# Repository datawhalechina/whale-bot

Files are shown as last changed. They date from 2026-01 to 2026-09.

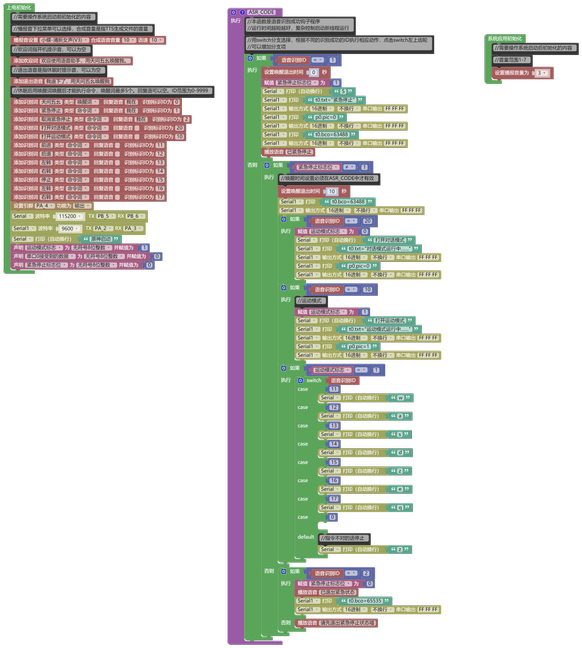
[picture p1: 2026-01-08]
WhaleBot智能鲸鱼小车/hardware/天问ASRPRO/天问ASRPRO.png

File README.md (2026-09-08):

# 🐳 WhaleBot 智能鲸鱼小车 (ESP32-S3 AI Robot)

**WhaleBot** 是一个基于 **ESP32-S3** 的全向移动 AI 机器人项目。它集成了 **Coze (扣子) 大模型**、**百度语音技术**、**麦克纳姆轮**全向运动控制以及**串口触摸屏**，实现了“听、说、想、动、看”一体化的智能交互体验。

---

### 🤝 Datawhale x 星芯工坊 | AI 硬件跟班学习

## 📚 开发教程 (Documentation)

本项目联合国内最大的 AI 开源社区 **Datawhale** 发起【AI 硬件入门跟班学习】活动！

Datawhale 致力于构建“For the learner, 构建 AI 学习者的开源社区”，汇聚了众多 AI 领域的专家与爱好者。

本次课程将带领大家从零开始，手搓一台属于自己的 AI 机器人。

我们编写了保姆级的开发教程，涵盖硬件选型、PCB 设计原理、代码注释及组装教程，并且会在后续配上视频教程。

👉 DataWhale官网教程链接**https://www.datawhale.cn/learn/summary/268** 👈

👉DataWhale跟班学习群👈

  a497525bfc7f890d2fe31357c8119220

如果这一期跟班学习人数已满怎么办？没关系，你可以加入我们的项目交流微信群，同样可以得到技术和硬件支持！

  

### 🛍️ 新手无忧套件

为了让初学者免去元器件采购发货慢、型号买错的烦恼，我们提供了**一站式全套件**（包含 3D 打印外壳、PCB 成品/半成品、电机、电池及所有电子料）。这些物料消息会在跟班学习官方群和我们的项目讨论群中同步更新，可以在群内咨询~

---

## 🛠️ 硬件架构

### 硬件清单
*   **主控**：ESP32-S3-DevKitC (N16R8)
*   **驱动**：TB6612FNG 2片
*   **执行器**：N20 减速电机 (12V 300RPM) 4个 + 麦克纳姆轮 4个（一套）
*   **音频**：INMP441 麦克风 + MAX98357A 功放 ＋ 
*   **电源**：12V 锂电池 + TPS5430 降压模块
*   **交互**：串口触摸屏 / 天问 ASRPRO 开发板
*   ps：电子器件部分如需自行购买请参考前文提到的“Datawhale官网开发教程”（后简称“教程”）第一大章“DIY所需硬件”的购买推荐
*   **外形**：详见docs/外壳打印文件
*   **PCB**：详见hardware/PCB及原理图

---

## 💻 复刻：快速上手指南

### 一. 硬件部分组装
1.准备好pcb板，按照板上引脚位置指示连接电子器件。
ps：若自行打板请参照hardware/Bom表购买相关电子元件并自行焊接。
2.外壳组装，外壳前后端与底板留有固定贴，方便拆卸调试，外壳文件详见docs/外壳打印。

### 二. esp32-s3程序部分
1.下载Arduino IDE（推荐版本2.1.4及以上）。
2.下载esp32芯片包，离线下载包位于firmware/esp32芯片包，如果不会离线下载请参考“教程”第三大章“软件部分”。
3.安装支持库如下
<base64.hpp> （建议版本1.3.0） 
<ArduinoJson.h> （建议版本7.4.1）
<UrlEncode.h> （建议版本1.0.1）
4.在烧录代码前按照下图所示进行相应选项的勾选！！

代码文件位于firmware/WhaleBot_Main.ino。

---

## 🤝 致谢

本项目由MeetAI实验室发起并完成项目开发，历时9个月最终成功制作出WhaleBot AI鲸鱼小车，并制作了一套完整的教程。在此衷心感谢Datawhale社区，全体参与开发的小伙伴，提供帮助的指导老师和同仁们。MeetAI实验室是来自福州大学的计算机学院的实验室，创立于2024年，致力于打造一个有趣好玩多元的104。


                                                
    实验室的开发者们

开发者名单

项目总负责人：林镐轩

项目开发：林镐轩，尚启峰，解皓喆

二次开发：林镐轩，Neil·Bauman，猫猫草，gtxylt，kyle

教程制作：林镐轩，kyle，小班，青莳与空，Neil·Bauman，猫猫草，李诗语，刘宣佑

如果你觉得这个项目有趣，请点击右上角的 ⭐️ **Star** 支持我们！

## 📄 License

[MIT License](LICENSE) © 2024 StarChip Workshop (星芯工坊)
```

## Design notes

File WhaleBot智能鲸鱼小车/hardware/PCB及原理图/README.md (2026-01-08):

# 🐋 WhaleBot 硬件设计与焊接指南

本文档说明了 WhaleBot 智能小车的硬件架构、PCB 设计规范及组装流程。

> 🌟 **欢迎加入【星芯工坊】社区**
> 如果你在制作过程中遇到了硬件调试疑难或希望参与新功能共创，欢迎加入：
> *   **群名称**：星芯工坊
> *   **QQ群号**：[571656123]

---

## 📐 1. PCB 设计与布线规范

在根据原理图进行 PCB 布局布线时，请务必遵循以下物理特性要求：

### 1.1 电源路径与线宽
根据原理图，电路包含三级电压，需按电流大小分配线宽：
*   **12V 动力线 (VBAT_12V)**：由 DC-005 输入，经过 SW1 开关和 F1 保险丝，直通两个 TB6612 的 VM 脚。建议线宽 **≥ 40mil**。
*   **5V 主供电 (+5V)**：经 U78 一级降压输出，供给 ASRPRO、串口屏和 MAX98357 功放。建议线宽 **≥ 25mil**。
*   **3.3V 逻辑电 (3V3)**：由 H78 (AMS1117 模块) 二级降压输出，供给 ESP32-S3 和 INMP441 麦克风。建议线宽 **≥ 15mil**。

### 1.2 信号完整性布局
1.  **音频保护**：U5 (麦克风) 和 U6 (功放) 属于敏感模拟/数字混合信号，应尽量远离 U3/U4 (电机驱动) 的高频 PWM 走线。
2.  **地线铺铜**：建议全板大面积铺 GND 铜箔，以降低阻抗并辅助散热。

---

## 🧩 2. 元器件清单 (BOM)

请对照原理图各功能框图准备以下元件：

### A. 核心模块
*   **MCU**: ESP32S3-DevKitC - 1个
*   **语音模块**: ASRPRO51 天问开发板 - 1个
*   **电机驱动**: TB6612FNG (正面插接) - 2个 (U3, U4)

### B. 电源与保护
*   **保险丝 (F1)**: SMD0805-050C-30V (0.5A/30V 自恢复) - 1个
*   **防反接/续流 (D1, D2)**: SS34 (肖特基二极管) - 2个
*   **一级降压 (U78)**: 12V 转 5V 降压模块 (4引脚封装) - 1个
*   **二级降压 (H78)**: PM254V-11-03 (AMS1117-3.3 模块) - 1个
*   **滤波电容 (C1)**: 100nF (104) 陶瓷电容 - 1个
*   **接插件**: DC-005 电源座、KCD1-101 开关、KF301R-5.0-2P 端子 (4个)

### C. 音频与交互
*   **麦克风 (U5)**: INMP441 I2S 模块 - 1个
*   **功放 (U6)**: MAX98357A I2S 模块 - 1个
*   **串口屏接口 (H1)**: 2.54mm 4P 排针 - 1个

---

## 🔌 3. 硬件引脚对应表 (严格对照原理图)

### 3.1 电机驱动 (ESP32 -> TB6612)
| 轮位 | 引脚功能 | ESP32-S3 引脚 |
| :--- | :--- | :--- |
| **左前 (FL)** | AIN1/AIN2 / PWMA | IO41 / IO42 / **IO40** |
| **右前 (FR)** | BIN1/BIN2 / PWMB | IO39 / IO38 / **IO48** |
| **左后 (RL)** | AIN1/AIN2 / PWMA | IO11 / IO10 / **IO12** |
| **右后 (RR)** | BIN1/BIN2 / PWMB | IO14 / IO13 / **IO21** |

### 3.2 音频系统 (ESP32 I2S)
*   **麦克风 (INMP441)**: WS -> **IO5** | SD -> **IO6** | SCK -> **IO4**
*   **功放 (MAX98357)**: LRC -> **IO16** | BCLK -> **IO8** | DIN -> **IO7**

### 3.3 串口通信 (ESP32-ASRPRO-屏幕)
*   **ESP32 侧**: TX -> **IO17** | RX -> **IO18**
*   **通信对象**: 该总线同时挂载 ASRPRO 的 PA2/PA3 及串口屏的 TX/RX。

---

## 👨‍🏭 4. 焊接与上电检查流程

### 4.1 焊接要点
1.  **高度优先**：先焊接贴片 F1、D1、D2 和 C1，再焊接排母和接线端子。
2.  **方向确认**：
    *   **D1/D2** 极性带杠的一端为负极，严禁焊反。
    *   **TB6612** 模块安装时，确认其 VM 脚对应原理图中的 12V 供电方向。

### 4.2 关键电压测试 (通电前必测)
在插入 ESP32 和模块前，接入 12V 电源，使用万用表测量排母：
1.  测量 `+5V` 与 `GND`：应稳定在 **5V ± 0.2V**。
2.  测量 `3V3` 与 `GND`：应稳定在 **3.3V ± 0.1V**。
3.  测量 `VM` (电机驱动排母第16脚)：应为 **12V** 电池电压。

---

## ⚠️ 常见问题排查 (FAQ)

**Q1: 电机不工作，但代码逻辑正常？**
*   检查 TB6612 的 `STBY` 引脚是否正确接入 3.3V。
*   检查 F1 保险丝是否因瞬时大电流熔断。

**Q2: 麦克风有严重杂音？**
*   检查 U5 的电源是否接在 3.3V（原理图设计），若误接 5V 会导致芯片性能衰减或烧毁。
*   确认电路板上麦克风附近的走线是否有高频干扰。

**Q3: 语音模块与串口屏冲突？**
*   原理图上 ASRPRO 与屏幕共用总线。请确保两者不会同时发送数据，或通过代码分配不同的握手逻辑。

---

**星芯工坊 - WhaleBot 硬件小组**
*版本：V1.0 | 日期：2026-01-07*

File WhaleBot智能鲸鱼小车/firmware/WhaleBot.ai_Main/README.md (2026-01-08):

# 🐋 WhaleBot.ai 固件说明 (WhaleBot.ai_Main)

本文档详细说明了 WhaleBot 智能鲸鱼小车主控程序（`WhaleBot.ai_Main.ino`）的编译环境配置、依赖库安装及代码逻辑。

## 🛠️ 1. 开发环境配置 (Arduino IDE)

本项目基于 **ESP32-S3** 芯片开发，为了确保程序能正常运行（特别是录音和长文本处理），**必须**正确配置 PSRAM。

### 1.1 安装开发板支持包
*   打开 Arduino IDE -> `文件` -> `首选项`。
*   在“附加开发板管理器网址”中添加：
    `https://espressif.github.io/arduino-esp32/package_esp32_index.json`
*   点击 `工具` -> `开发板` -> `开发板管理器`，搜索 **ESP32 by Espressif System** 并安装 (推荐版本 3.3.5)。

### 1.2 关键参数配置 (至关重要 ⚠️)
请按照以下步骤配置 `工具 (Tools)` 菜单：

1.  **开发板 (Board)**: 选择 `ESP32S3 Dev Module`。
2.  **USB CDC On Boot**: 选择 `Enabled` (这样串口监视器才能看到打印信息)。
3.  **Flash Mode**: 选择 `QIO 80MHz`。
4.  **PSRAM**: **必须选择 `OPI PSRAM`**。
    *   *解释*：本项目录音缓存和 Base64 编码需要大量内存，内部 SRAM 不够用，必须开启外部 8MB PSRAM。
    *   *注意*：开启 OPI PSRAM 后，GPIO 35, 36, 37 将被占用，不可用于其他功能（代码中已避开这些引脚）。

---

## 📚 2. 依赖库安装

在编译代码前，请在 Arduino IDE 的 `项目` -> `加载库` -> `管理库` 中搜索并安装以下第三方库：

*   **ArduinoJson** (必选)
    *   说明：用于解析 Coze 大模型和百度 API 返回的 JSON 数据。
    *   版本：推荐 6.x 版本。
*   **UrlEncode** (必选)
    *   说明：用于将中文文本转换为 URL 编码格式，以便发送 HTTP 请求。

*注：`HTTPClient`, `WiFi`, `driver/i2s` 等库包含在 ESP32 开发板包中，无需单独下载。*

---

## 🔌 3. 硬件引脚速查表 (Pinout)

如果在画 PCB 或连线时需要参考，请以本表为准（与代码定义一致）。

### 3.1 外部接口 (串口通信)
用于连接天问 ASR 或蓝牙模块：
*   **TX (模块端)** -> 接 ESP32 **GPIO 18** (RX)
*   **RX (模块端)** -> 接 ESP32 **GPIO 17** (TX)

### 3.2 音频系统 (I2S)

**麦克风 (INMP441)**
*   **SCK** (时钟) -> **GPIO 4**
*   **WS** (字选) -> **GPIO 5**
*   **SD** (数据) -> **GPIO 6**

**功放 (MAX98357A)**
*   **BCLK** (位时钟) -> **GPIO 8** (*注意：此处非默认的15*)
*   **LRC** (左右声道) -> **GPIO 16**
*   **DIN** (数据入) -> **GPIO 7**

### 3.3 电机驱动 (TB6612 x2)

**左前轮 (FL)**
*   IN1: **42**
*   IN2: **41**
*   PWM: **40**

**右前轮 (FR)**
*   IN1: **39**
*   IN2: **38**
*   PWM: **48** (*注意：避开了 OPI PSRAM 引脚*)

**左后轮 (RL)**
*   IN1: **10**
*   IN2: **11**
*   PWM: **12**

**右后轮 (RR)**
*   IN1: **13**
*   IN2: **14**
*   PWM: **21**

---

## 🧠 4. 代码逻辑架构

本固件采用 **状态机 (State Machine)** 架构，确保小车在不同模式下互不干扰。

### 4.1 核心状态
1.  **MODE_IDLE (待机)**
    *   停止所有电机和录音，仅监听串口指令。
    *   收到 `停止` 指令后强制回到此状态。
2.  **MODE_VOICE (语音)**
    *   进入后等待 `开始聊天` 指令触发。
    *   **流程**：VAD 录音 (说话即录，说完即停) -> 回放录音 -> 百度 STT (转文字) -> Coze LLM (AI思考) -> 百度 TTS (语音合成并播放)。
3.  **MODE_MOTION (运动)**
    *   接收串口 `W/A/S/D` 等指令控制麦克纳姆轮全向移动。
    *   支持 `点动模式` (动2秒自动停) 和 `持续模式` (一直动直到停止)。

### 4.2 串口通信协议
*   **波特率**: `115200`
*   **结束符**: 每一条指令必须以换行符 `\n` 结尾。
*   **指令示例**:
    *   `打开对话模式` —— 进入语音状态
    *   `开始聊天` —— 触发录音
    *   `W` —— 前进
    *   `停止` —— 全局急停

---

## 📝 5. 使用前必读

在上传代码前，请务必在 `WhaleBot.ai_Main.ino` 文件的顶部 **用户配置区** 填入你自己的信息：

1.  **WiFi**: 修改 SSID 和 密码。
2.  **百度智能云**: 填入 API Key 和 Secret Key (用于语音服务)。
3.  **Coze (扣子)**: 填入 PAT Token 和 Bot ID (用于 AI 对话)。

> 详细的 API 获取教程请查看目录下的：`firmware/百度 和 COZE API获取/Readme.md`

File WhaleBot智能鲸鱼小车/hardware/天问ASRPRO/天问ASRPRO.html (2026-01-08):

# 🎙️ ASRPRO 2.0 + 天问 Block 开发指南

  

本文档旨在为开发者提供 ASRPRO 2.0 语音模块与天问 Block 开发平台的集成概览。重点阐述系统架构、核心运行逻辑以及外设通信的基础配置。

## 1. 平台概述 (Overview)

### 🧩 ASRPRO 2.0 硬件平台

ASRPRO 是一款高度集成的离线语音识别开发板，专为语音交互场景设计。其硬件架构具有以下特点：

- 核心集成：板载高性能语音处理模块，内置神经网络加速单元。
- 声学前端：集成高灵敏度麦克风接口与功率放大器（Power Amp），支持直接驱动扬声器。
- 丰富外设：
  - 通信接口：集成串口 (UART)、IIC 总线。
  - 控制与采集：提供 ADC（模数转换）、硬件定时器等资源。
- 主要用途：广泛应用于离线语音识别、简单的语音对话交互以及智能家居控制。

### 💻 天问 Block 软件平台

天问 Block (Tianwen Block) 是 ASRPRO 系列的官方开发环境，旨在通过图形化界面降低开发门槛。

- 编程模式：采用类 Sketch、Mixly 的积木式图形化编程界面。
- 功能实现：支持通过拖拽积木实现复杂的逻辑控制，底层自动编译为高效的执行代码。

## 2. 核心运行机制 (Core Mechanism)

理解 ASRPRO 的程序生命周期是开发的关键。在天问 Block 环境下，系统的执行逻辑遵循以下严格顺序：

初始化阶段 系统上电后，首先执行上电初始化，紧接着执行系统应用初始化。

正常运行阶段 完成初始化后，系统进入正常运行状态（主循环），处于持续监听模式。

事件触发机制 当系统检测到语音唤醒或识别到预设的命令词时，会执行 asrcore 核心程序一次。所有的语音识别后处理逻辑（如回复语播放、信号输出）均应在此事件中实现。

## 3. 外设与通信配置 (Peripherals & Communication)

本项目主要利用 串口 (UART) 外设实现 ASRPRO 与外部设备（如串口屏、ESP32-S3 主控）的数据交互。

### 🔌 串口资源概览

ASRPRO 硬件上共包含 3 个独立串口，开发者需根据实际需求进行配置。

### ⚙️ 配置规范

在使用串口外设前，必须在初始化阶段完成以下参数定义：

1. 初始化要求：
  - 串口功能默认关闭，必须在程序启动时显式执行初始化模块。
2. 波特率配置：
  - 支持配置为固定的标准波特率档位1200，4800，9600，19200，38400，57600，115200，推荐配置为最高115200。
  - 注意：通信双方的波特率必须保持严格一致。
3. 引脚定义：
  - 串口的 TX/RX 引脚由硬件外设控制器直接决定。
  - 不可修改性：引脚映射是固定的，在使用时，需要注意和现有的引脚冲突情况。

你好

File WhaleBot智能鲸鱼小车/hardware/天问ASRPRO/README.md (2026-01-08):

# 🎙️ ASRPRO 2.0 + 天问 Block 开发指南

  

本文档旨在为开发者提供 ASRPRO 2.0 语音模块与天问 Block 开发平台的集成概览。重点阐述系统架构、核心运行逻辑以及外设通信的基础配置。

---

## 1. 平台概述 (Overview)

### 🧩 ASRPRO 2.0 硬件平台
ASRPRO 是一款高度集成的离线语音识别开发板，专为语音交互场景设计。其硬件架构具有以下特点：

*   **核心集成**：板载高性能语音处理模块，内置神经网络加速单元。
*   **声学前端**：集成高灵敏度麦克风接口与功率放大器（Power Amp），支持直接驱动扬声器。
*   **丰富外设**：
    *   **通信接口**：集成串口 (UART)、IIC 总线。
    *   **控制与采集**：提供 ADC（模数转换）、硬件定时器等资源。
*   **主要用途**：广泛应用于离线语音识别、简单的语音对话交互以及智能家居控制。

### 💻 天问 Block 软件平台
天问 Block (Tianwen Block) 是 ASRPRO 系列的官方开发环境，旨在通过图形化界面降低开发门槛。

*   **编程模式**：采用类 Sketch、Mixly 的积木式图形化编程界面。
*   **功能实现**：支持通过拖拽积木实现复杂的逻辑控制，底层自动编译为高效的执行代码。

---

## 2. 核心运行机制 (Core Mechanism)

理解 ASRPRO 的程序生命周期是开发的关键。在天问 Block 环境下，系统的执行逻辑遵循以下严格顺序：

> **初始化阶段**
> 系统上电后，首先执行**上电初始化**，紧接着执行**系统应用初始化**。

> **正常运行阶段**
> 完成初始化后，系统进入正常运行状态（主循环），处于持续监听模式。

> **事件触发机制**
> 当系统检测到**语音唤醒**或识别到预设的**命令词**时，会执行 `asrcore` 核心程序一次。所有的语音识别后处理逻辑（如回复语播放、信号输出）均应在此事件中实现。

---

## 3. 外设与通信配置 (Peripherals & Communication)

本项目主要利用 **串口 (UART)** 外设实现 ASRPRO 与外部设备（如串口屏、ESP32-S3 主控）的数据交互。

### 🔌 串口资源概览
ASRPRO 硬件上共包含 **3 个独立串口**，开发者需根据实际需求进行配置。

### ⚙️ 配置规范
在使用串口外设前，必须在初始化阶段完成以下参数定义：

1.  **初始化要求**：
    *   串口功能默认关闭，必须在程序启动时显式执行初始化模块。

2.  **波特率配置**：
    *   支持配置为固定的标准波特率档位1200，4800，9600，19200，38400，57600，115200，推荐配置为最高115200。
    *   *注意：通信双方的波特率必须保持严格一致。*

3.  **引脚定义**：
    *   串口的 TX/RX 引脚由硬件外设控制器直接决定。
    *   **不可修改性**：引脚映射是固定的，在使用时，需要注意和现有的引脚冲突情况。

---

## 4. 语音指令表 (Voice Command Table)

以下为本项目预设的语音识别指令集。指令分为**唤醒**、**安全控制**、**模式切换**及**运动控制**四大类。

| 语音指令 | 执行内容 (TTS/Action) | 指令摘要 |
| :--- | :--- | :--- |
| **天问五幺** | 🔊 播报：“我在” | **设备唤醒词**，用于激活语音交互状态。 |
| **紧急停止** | 🔇 无语音回复 | **最高优先级指令**，触发急停逻辑，中断当前所有动作。 |
| **取消紧急停止** | 🔇 无语音回复 | 解除急停锁定状态，恢复设备待机。 |
| **打开对话模式** | 🔇 无语音回复 | 切换系统至对话交互逻辑，准备接收聊天指令。 |
| **开始聊天** | 🔇 无语音回复 | 触发聊天功能模块。 |
| **打开运动模式** | 🔇 无语音回复 | 切换系统至运动控制逻辑，激活电机/底盘控制。 |
| **前进** | 🔇 无语音回复 | 控制设备向前移动。 |
| **后退** | 🔇 无语音回复 | 控制设备向后移动。 |
| **左平移** | 🔇 无语音回复 | 控制麦克纳姆轮/全向轮底盘向左平移。 |
| **右平移** | 🔇 无语音回复 | 控制麦克纳姆轮/全向轮底盘向右平移。 |
| **停止** | 🔇 无语音回复 | 结束当前移动指令，设备归零/刹车。 |
| **左转** | 🔇 无语音回复 | 控制设备原地向左旋转。 |
| **右转** | 🔇 无语音回复 | 控制设备原地向右旋转。 |
| **设置为持续运动状态** | 🔇 无语音回复 | 更改运动逻辑为“保持当前动作直到收到停止指令”。 |
| **退出持续运动状态** | 🔇 无语音回复 | 恢复默认运动逻辑（如点动模式或定时停止）。 |

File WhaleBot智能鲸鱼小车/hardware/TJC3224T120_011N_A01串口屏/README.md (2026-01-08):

这份文档已经按照你的要求进行了重新架构和内容扩充，采用了更加专业、美观的 Markdown 格式，增强了逻辑性和可读性。

---

# ASRPRO 与淘晶驰串口屏开发指南

> **导语**：本指南旨在帮助开发者快速掌握 ASRPRO 语音芯片与淘晶驰（TJC）串口屏的联动开发。通过本方案，你可以实现“语音控制显示”与“屏幕触摸反馈”的深度交互。

---

## 一、 序章：思维的转变

如果你曾经使用过 **IIC 屏幕、SPI 屏幕或并口屏**，请在开始前**暂时忘掉**它们的开发逻辑。

*   **传统屏幕**：主控（MCU）负责计算每一个像素点，刷新波形，占用大量内存和运算资源。
*   **淘晶驰串口屏**：属于“智能屏”。UI 逻辑、图片渲染、字体显示、甚至简单的逻辑运算都在屏幕内部的处理器上完成。

**核心差异**：
*   **开发重心**：从“在代码里画图”转变为“在上位机软件（USART-HMI）里拖拽控件”。
*   **通信逻辑**：单片机只需通过串口发送一行简单的文本指令（如 `t0.txt="123"`），即可改变显示内容。

---

## 二、 硬件连接方案

ASRPRO 与串口屏通过 TTL 串口进行全双工通信。

### 2.1 标准接线表
| ASRPRO 引脚 | 串口屏引脚 | 说明 |
| :--- | :--- | :--- |
| **5V** | **5V** | 供电（务必保证电源电流充足，背光全亮时耗电较大） |
| **GND** | **GND** | 共地 |
| **PA3 (TX)** | **RX** | ASRPRO 发送，屏幕接收 |
| **PA2 (RX)** | **TX** | 屏幕发送，ASRPRO 接收 |

> **⚠️ 注意**：
> 1. 请务必交叉连接（TX 接 RX，RX 接 TX）。
> 2. 如果使用自定义 PCB，请直接将 ASRPRO 和屏幕插入对应插槽，无需额外接线。

---

## 三、 软件环境配置

开发串口屏的第一步是安装官方配套的设计软件。

1.  **软件名称**：USART-HMI
2.  **下载地址**：[淘晶驰官方下载页](http://wiki.tjc1688.com/download/usart_hmi.html)
3.  **主要功能**：
    *   界面 UI 设计（拖拽式）。
    *   图片、字库素材管理。
    *   指令集调试（模拟器）。
    *   固件下载。

---

## 四、 串口屏开发流程

串口屏的开发遵循“**先设计资产，后逻辑控制**”的原则。

### 4.1 素材准备与导入
*   **字库导入**：必须在软件内生成并导入字库（.zi格式），否则无法显示汉字。
*   **图片素材**：建议在导入前通过 PS 等软件裁剪好对应屏幕的分辨率。
*   **Flash 管理**：所有图片和字库都占用屏幕的 Flash 空间。**切记：** 删除不用的素材，避免超出存储限制导致下载失败。

### 4.2 核心概念：页面 (Page) 与控件 (Control)
*   **页面 (Page)**：类似幻灯片，一个工程可以有多个页面（如：主页、设置页、数据监测页）。
*   **控件 (Control)**：
    *   `t0` (文本控件)：显示字符串。
    *   `n0` (数字控件)：显示数值。
    *   `b0` (按钮控件)：可交互对象。
    *   `p0` (图片控件)：静态或动态图片展示。

### 4.3 属性与指令
每个控件都有自己的属性，开发者可以通过指令实时修改它们：
*   **静态修改**：在 HMI 软件右侧属性栏直接设置。
*   **动态修改**（由 ASRPRO 发送）：
    *   修改文本：`t0.txt="开启空调"`
    *   修改背景色：`b0.bco=63488` (红色)
    *   切换页面：`page 1`

---

## 五、 通信协议详解

### 5.1 数据结束符 (至关重要)
淘晶驰串口屏的所有指令必须以 **三个连续的十六进制数 `0xFF`** 结尾。
*   **错误示例**：`t0.txt="OK"`
*   **正确示例**：`t0.txt="OK"\xFF\xFF\xFF`

### 5.2 交互逻辑
1.  **ASRPRO → 屏幕**：ASRPRO 识别到语音后，发送指令修改屏幕状态。
2.  **屏幕 → ASRPRO**：用户点击屏幕按钮，屏幕通过串口向 ASRPRO 发送自定义字符串（例如 `clicked_btn1`），ASRPRO 接收并执行相应动作。

*   **详细指令集参考**：[官方指令文档](http://wiki.tjc1688.com/commands/index.html)

---

## 六、 进阶：触摸交互与脚本

串口屏不仅仅是一个显示器，它还具备一定的**逻辑运算能力**。

*   **事件触发**：你可以为按钮设置“按下事件”或“弹起事件”。
*   **内部脚本**：在屏幕端编写简单的代码。
    *   *场景*：点击按钮 A，让文本 t0 的数值自增 1。
    *   *屏幕端代码*：`n0.val=n0.val+1`
*   **优势**：这种简单的 UI 交互逻辑直接在屏幕端运行，无需 ASRPRO 参与，响应速度极快且节省串口带宽。

---

## 七、 调试建议

1.  **使用模拟器**：在 USART-HMI 软件中，点击“运行”可以使用模拟器。你可以通过电脑串口连接 ASRPRO，在不烧录屏幕的情况下调试代码。
2.  **波特率匹配**：淘晶驰屏幕默认波特率通常为 `9600`，但在复杂界面开发中，建议将其设置为 `115200` 以获得更流畅的刷新体验。
3.  **隔离测试**：先用“USB转TTL”模块连接电脑和屏幕，确认指令能控制屏幕，再连接 ASRPRO。

---

**结语**：ASRPRO 与串口屏的结合，是实现“声色兼备”智能硬件的最简方案。只需掌握核心的串口指令发送，你就能做出媲美手机 App 的交互界面。

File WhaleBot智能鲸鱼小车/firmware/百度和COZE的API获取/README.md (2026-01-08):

# 🔑 API Key 获取简易指南

---

本项目需要 **百度智能云**（负责听和说）和 **Coze 扣子**（负责思考）的 API 密钥才能运行。请按照以下步骤获取，并将它们填入 `WhaleBot.ai_Main.ino` 代码中。

> ℹ️ **提示**：本文仅为快速 Key 获取指引，详细的开发与代码解析请参考仓库内的完整技术文档。

---

## 1. 百度智能云 (语音识别 & 合成)

用于实现小车的“耳朵”（STT）和“嘴巴”（TTS）。

1.  **注册登录**：访问 [百度智能云控制台](https://console.bce.baidu.com/ai/)。
2.  **创建应用**：
    *   进入“语音技术”控制台。
    *   点击“创建应用”。
    *   **接口选择**：务必勾选 **“短语音识别”** 和 **“在线语音合成”**。
3.  **获取密钥**：
    *   创建成功后，在应用列表中找到你的应用。
    *   复制 **`API Key`** 和 **`Secret Key`**。

---

## 2. Coze 扣子 (AI 大模型)

用于实现小车的“大脑”，进行自然语言对话。

1.  **注册登录**：访问 [Coze 国内版](https://www.coze.cn/)。
2.  **创建 Bot**：
    *   创建一个新的智能体 (Bot)，编写提示词（例如：“你是一个叫乐迪的智能小车...”）。
    *   **重要**：配置完成后，必须点击右上角的 **“发布”**，否则 API 无法调用。
3.  **获取 Bot ID**：
    *   进入你的 Bot 开发页面。
    *   看浏览器地址栏：`https://www.coze.cn/space/xxxx/bot/73123456789...`
    *   链接末尾的那串数字就是 **`Bot ID`**。
4.  **获取 PAT (访问令牌)**：
    *   点击左下角头像 -> `扣子 API` -> `API 令牌`。
    *   点击“添加令牌” (Personal Access Token)。
    *   勾选权限（建议全选或至少包含 Bot 对话权限），复制生成的 **`PAT`** 字符串。

---

## 📝 填入代码

拿到上述 4 个密钥后，请打开 Arduino IDE 中的 `WhaleBot.ai_Main.ino`，找到顶部的 **用户配置区** 进行替换：

```cpp
// 百度配置
const char* baidu_api_key    = "复制你的API Key到这里";       
const char* baidu_secret_key = "复制你的Secret Key到这里"; 

// Coze 配置
const String coze_apiKey = "复制你的PAT到这里"; 
const String botId       = "复制你的Bot ID到这里";

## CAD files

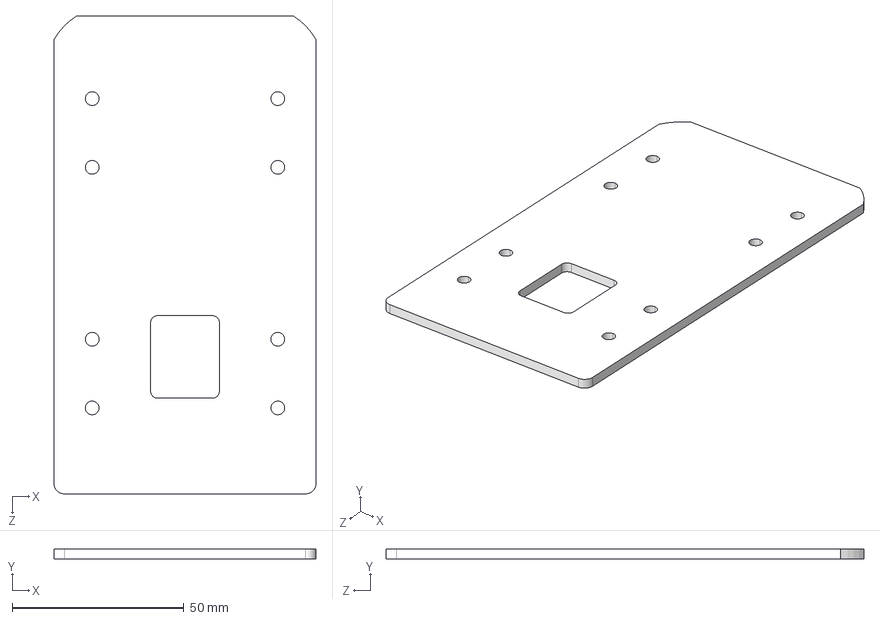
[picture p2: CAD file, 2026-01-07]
WhaleBot智能鲸鱼小车/docs/外壳文件/底板.STEP
76.2 x 3.00 x 139.0 mm

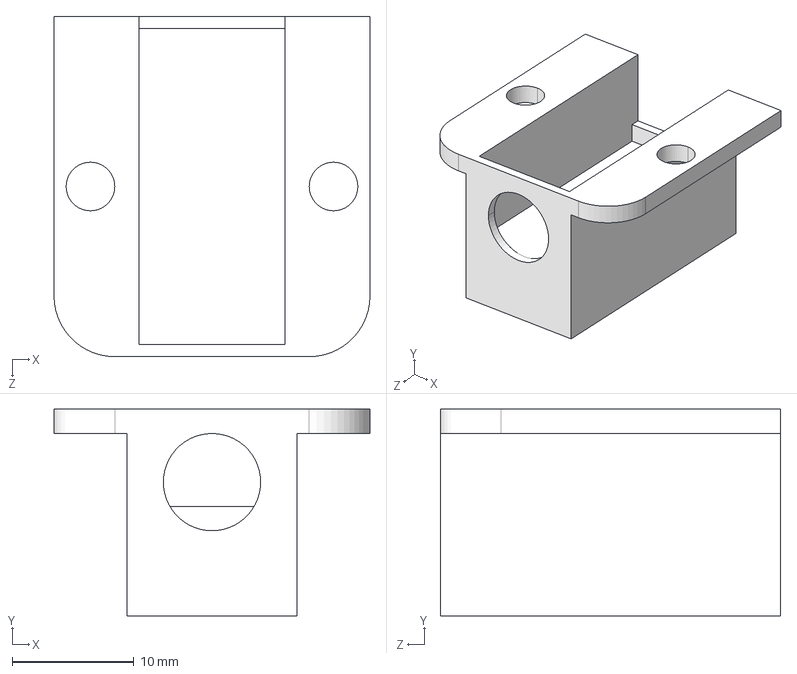
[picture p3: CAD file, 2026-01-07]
WhaleBot智能鲸鱼小车/docs/外壳文件/n20电机固定架.STEP
26.0 x 17.0 x 28.0 mm

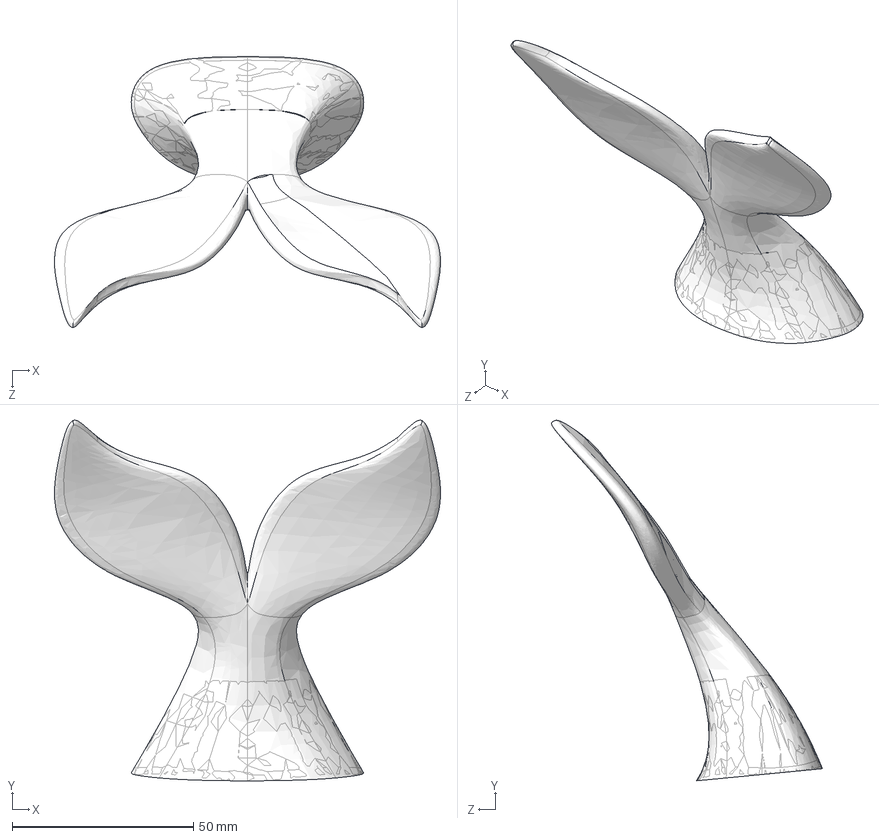
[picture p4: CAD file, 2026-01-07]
WhaleBot智能鲸鱼小车/docs/外壳文件/尾巴.STEP
106.5 x 99.5 x 74.8 mm

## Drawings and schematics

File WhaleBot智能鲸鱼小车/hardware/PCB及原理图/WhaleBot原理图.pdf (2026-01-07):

# 二级降压 5V -> 3.3V

电源输入及开关 | 一级降压 12V -> 5V

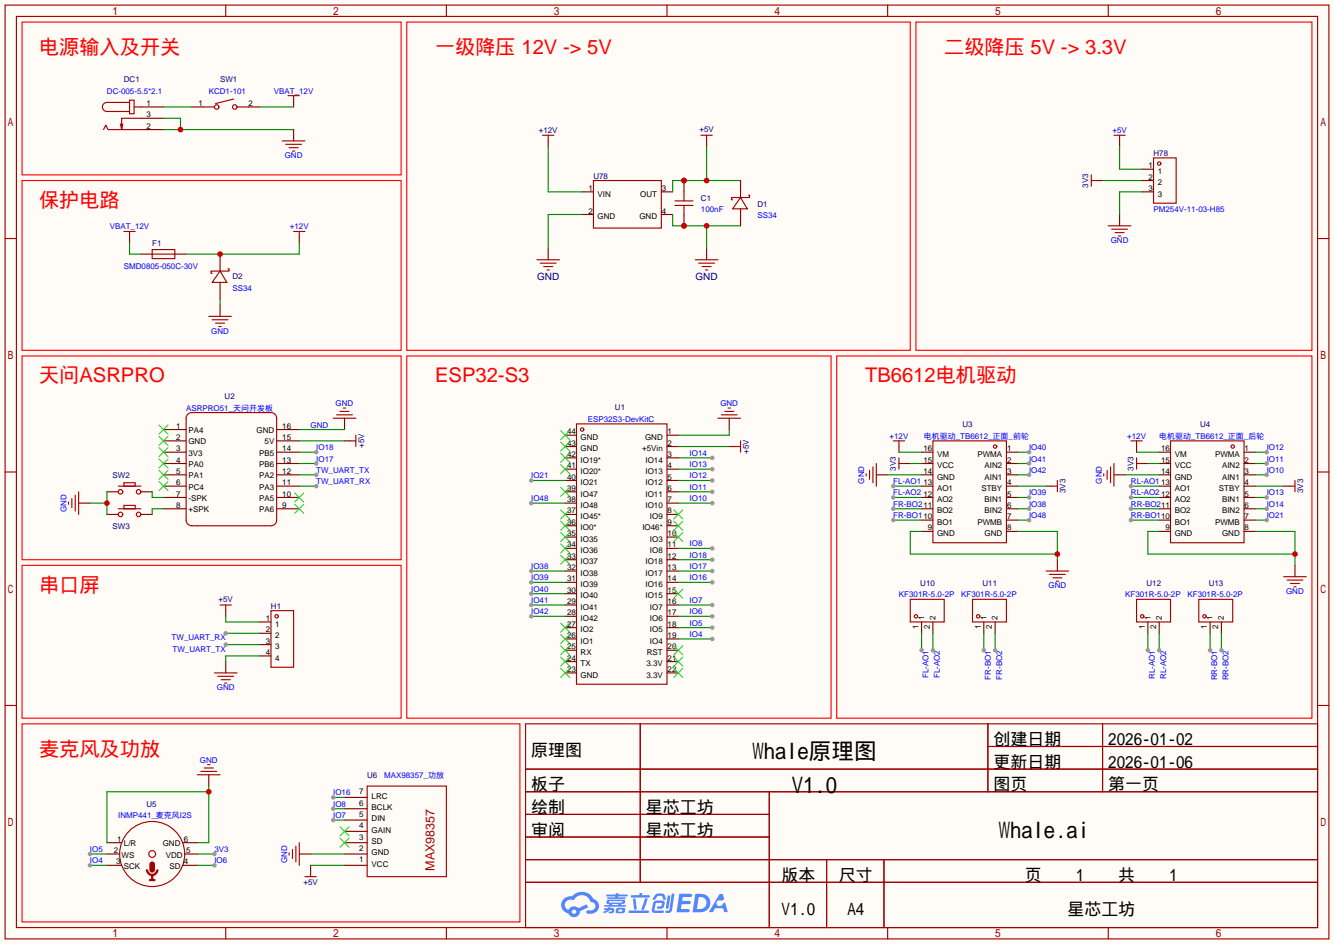
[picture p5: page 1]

原理图 | Whale原理图 | 创建日期 | 2026-01-02

更新日期 | 2026-01-06

板子 | V1.0 | 图页 | 第一页
绘制 | 星芯工坊 | Whale.ai
审阅 | 星芯工坊

V1.0 | A4 | 星芯工坊

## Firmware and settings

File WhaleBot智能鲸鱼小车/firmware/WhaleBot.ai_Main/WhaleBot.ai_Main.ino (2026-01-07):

 * Description:
 *   这是一个基于 ESP32-S3 的智能鲸鱼小车项目，集成了：
 *   1. 麦克风阵列录音 (I2S, INMP441)
 *   2. 语音活动检测 (VAD)
 *   3. 百度语音识别 (STT)
 *   4. Coze (扣子) 大模型对话 (LLM)
 *   5. 百度语音合成 (TTS)
 *   6. 麦克纳姆轮全向运动控制 (TB6612)
 *   7. 串口指令控制 (状态机)
 * 
 * Hardware Pinout (硬件接线速查表):
 * --------------------------------------------------------------------------------------
 * 1. 外部串口 (连接 蓝牙/语音模块/上位机):
 *    TX -> ESP32 GPIO 18 (RX)
 *    RX -> ESP32 GPIO 17 (TX)
 *    GND -> GND (共地)
 * 
 * 2. 麦克风 (INMP441 - I2S0): 
 *    SCK -> GPIO 4
 *    WS  -> GPIO 5
 *    SD  -> GPIO 6
 * 
 * 3. 功放 (MAX98357A - I2S1): 
 *    BCLK -> GPIO 8
 *    LRC  -> GPIO 16
 *    DIN  -> GPIO 7
 * 
 * 4. 电机驱动 (TB6612 x2): 
 *    左前(FL): IN:42/41, PWM:40 
 *    右前(FR): IN:39/38, PWM:48 (注意: 避开 PSRAM 引脚 35-37)
 *    左后(RL): IN:10/11, PWM:12 
 *    右后(RR): IN:13/14, PWM:21
 * ======================================================================================
 */

#include <string.h>
#include <driver/i2s.h>
#include <WiFi.h>  
#include <HTTPClient.h>
#include <ArduinoJson.h>
#include <UrlEncode.h>

// =============================================================
//               PART 1: 用户配置区域 (User Configuration)
// =============================================================

// [WiFi 设置]
// TODO: 请修改为您的 WiFi 名称和密码
const char* ssid     = "YOUR_WIFI_SSID";    
const char* password = "YOUR_WIFI_PASSWORD"; 

// [百度智能云 API 配置]
// 用于语音识别(STT)和语音合成(TTS)
// 获取地址: https://console.bce.baidu.com/ai/
// TODO: 请填入您的百度 API Key 和 Secret Key
const char* baidu_api_key    = "YOUR_BAIDU_API_KEY";       
const char* baidu_secret_key = "YOUR_BAIDU_SECRET_KEY"; 
String baidu_access_token = ""; // 自动获取，无需手动填写

// [Coze (扣子) API 配置]
// 用于大模型对话逻辑
// 获取地址: https://www.coze.cn/
// TODO: 请填入您的 Coze PAT Token 和 Bot ID
const String coze_apiKey = "pat_YOUR_COZE_PAT_TOKEN"; 
const String botId       = "YOUR_COZE_BOT_ID";        

// [串口设置]
// 与外部模块通信的波特率
#define EXT_SERIAL_BAUD 115200 


// =============================================================
//               PART 2: 硬件引脚定义 (Hardware Pins)
// =============================================================

// --- 外部串口 ---
#define EXT_SERIAL_RX 18  
#define EXT_SERIAL_TX 17  

// --- 电机驱动 (TB6612) ---
#define PIN_FL_IN1 42 
#define PIN_FL_IN2 41 
#define PIN_FL_PWM 40 

#define PIN_FR_IN1 39
#define PIN_FR_IN2 38 
#define PIN_FR_PWM 48 // 注意: 使用 48 避开 OPI PSRAM 占用的 GPIO 35-37

#define PIN_RL_IN1 10
#define PIN_RL_IN2 11
#define PIN_RL_PWM 12

#define PIN_RR_IN1 13
#define PIN_RR_IN2 14
#define PIN_RR_PWM 21

// --- 麦克风 (I2S Input) ---
#define INMP441_WS 5
#define INMP441_SCK 4
#define INMP441_SD 6       

// --- 功放 (I2S Output) ---
#define MAX98357_LRC 16
#define MAX98357_BCLK 8 
#define MAX98357_DIN 7


// =============================================================
//               PART 3: 全局变量与系统参数
// =============================================================

HardwareSerial MySerial(1); // 定义硬件串口对象

// 系统运行状态机
enum SystemMode { 
  MODE_IDLE,    // 待机状态
  MODE_VOICE,   // 语音对话模式
  MODE_MOTION   // 运动控制模式
};
SystemMode currentMode = MODE_IDLE; 

// 语音模式控制标记
bool voiceTrigger = false; 

// 运动模式控制变量
bool isContinuous = false;      // false=点动模式(2s), true=持续模式
bool isMoving = false;          // 当前运动状态标记
unsigned long lastMoveTime = 0; // 上次运动指令的时间戳

// 音频参数
#define SAMPLE_RATE 16000
#define MAX_RECORD_SECONDS 15   // 最大录音时长(秒)
#define BUFFER_SIZE (SAMPLE_RATE * MAX_RECORD_SECONDS * 2) 

// VAD (语音活动检测) 参数
#define VAD_THRESHOLD 1000      // 音量阈值 (根据麦克风灵敏度调整)
#define VAD_SILENCE_MS 1000     // 静音超时判定 (ms)

// --- I2S 配置 (麦克风) ---
i2s_config_t i2sIn_config = {
  .mode = i2s_mode_t(I2S_MODE_MASTER | I2S_MODE_RX),
  .sample_rate = SAMPLE_RATE,
  .bits_per_sample = i2s_bits_per_sample_t(16),
  .channel_format = I2S_CHANNEL_FMT_ONLY_LEFT,
  .communication_format = i2s_comm_format_t(I2S_COMM_FORMAT_STAND_I2S),
  .intr_alloc_flags = ESP_INTR_FLAG_LEVEL1,
  .dma_buf_count = 8,
  .dma_buf_len = 1024
};

const i2s_pin_config_t i2sIn_pin_config = {
  .bck_io_num = INMP441_SCK,
  .ws_io_num = INMP441_WS,
  .data_out_num = -1,
  .data_in_num = INMP441_SD
};

// --- I2S 配置 (功放) ---
i2s_config_t i2sOut_config = {
  .mode = i2s_mode_t(I2S_MODE_MASTER | I2S_MODE_TX),
  .sample_rate = SAMPLE_RATE,
  .bits_per_sample = i2s_bits_per_sample_t(16),
  .channel_format = I2S_CHANNEL_FMT_ONLY_RIGHT,
  .communication_format = i2s_comm_format_t(I2S_COMM_FORMAT_STAND_I2S),
  .intr_alloc_flags = ESP_INTR_FLAG_LEVEL1,
  .dma_buf_count = 8,
  .dma_buf_len = 1024
};

const i2s_pin_config_t i2sOut_pin_config = {
  .bck_io_num = MAX98357_BCLK,
  .ws_io_num = MAX98357_LRC,
  .data_out_num = MAX98357_DIN,
  .data_in_num = -1
};


// =============================================================
//               PART 4: 函数声明 (Function Declarations)
// =============================================================
void setupMotors();
void stopMotors();
void controlMecanum(int x, int y, int w);
void setMotorSpeed(int pinIn1, int pinIn2, int pinPwm, int speed);
void handleSerialCommand();
void runVoiceMode();
void runMotionMode();

String getAccessToken(const char* api_key, const char* secret_key);
String ask_coze(const String& question);
String baiduSTT_Send(String access_token, uint8_t* audioData, int audioDataSize);
void baiduTTS_Send(String access_token, String text);
void playAudio(uint8_t* audioData, size_t audioDataSize);
void clearAudio(void);
void custom_base64_encode(char* output, uint8_t* input, int inputLen); 
void playSilence(); 


// =============================================================
//               PART 5: 主程序初始化 (Setup)
// =============================================================
void setup() {
  Serial.begin(115200);
  
  // 初始化外部控制串口
  MySerial.begin(EXT_SERIAL_BAUD, SERIAL_8N1, EXT_SERIAL_RX, EXT_SERIAL_TX);
  Serial.println("System Start");

  // 初始化电机
  setupMotors(); 

  // 连接 WiFi
  WiFi.begin(ssid, password);
  Serial.print("WiFi Connecting");
  while (WiFi.status() != WL_CONNECTED) {
    delay(500);
    Serial.print(".");
  }
  Serial.println("\nWiFi connected: " + WiFi.localIP().toString());

  // 初始化 I2S 驱动
  i2s_driver_install(I2S_NUM_0, &i2sIn_config, 0, NULL);
  i2s_set_pin(I2S_NUM_0, &i2sIn_pin_config);
  i2s_driver_install(I2S_NUM_1, &i2sOut_config, 0, NULL);
  i2s_set_pin(I2S_NUM_1, &i2sOut_pin_config);

  // 获取百度 Token
  baidu_access_token = getAccessToken(baidu_api_key, baidu_secret_key);
  Serial.println("Token: " + baidu_access_token);
  
  Serial.println("等待指令 (发送: '打开对话模式', '开始聊天', '打开运动模式', '停止')...");
}


// =============================================================
//               PART 6: 主循环 (Main Loop)
// =============================================================
void loop() {
  // 1. 处理串口指令 (最高优先级)
  handleSerialCommand();

  // 2. 根据状态机执行对应逻辑
  switch (currentMode) {
    case MODE_IDLE:
      delay(50);
      break;
    
    case MODE_VOICE:
      runVoiceMode(); 
      break;
      
    case MODE_MOTION:
      runMotionMode(); 
      break;
  }
}


// =============================================================
//               PART 7: 核心功能模块 (Core Modules)
// =============================================================

// --- [模块A] 串口指令处理 ---
void handleSerialCommand() {
  if (MySerial.available()) {
    String cmd = MySerial.readStringUntil('\n');
    cmd.trim(); 
    if (cmd.length() == 0) return;
    Serial.println("[CMD] " + cmd);

    // 1. 全局停止指令 (最高优先级)
    if (cmd == "stop" || cmd == "S") {
      stopMotors();
      currentMode = MODE_IDLE; 
      voiceTrigger = false;
      isMoving = false;    
      Serial.println(">>> [已停止] 回到待机");
      return; 
    }

    // 2. 模式切换指令
    if (cmd == "chatmode") {
      stopMotors();
      currentMode = MODE_VOICE;
      voiceTrigger = false;
      Serial.println(">>> [对话模式] 就绪");
      return;
    } 
    else if (cmd == "sportmode") {
      stopMotors(); 
      currentMode = MODE_MOTION;
      voiceTrigger = false;
      isContinuous = false; // 默认点动
      Serial.println(">>> [运动模式] 就绪 (默认点动)");
      return;
    }

    // 3. 待机状态屏蔽
    if (currentMode == MODE_IDLE) {
        Serial.println("!!! 待机中，请先选择模式");
        return;
    }

    // 4. 对话模式指令
    if (currentMode == MODE_VOICE) {
        if (cmd == "startchat") {
            voiceTrigger = true; 
            Serial.println(">>> 触发录音!");
        }
    } 
    // 5. 运动模式指令
    else if (currentMode == MODE_MOTION) {
        // 子模式切换
        if (cmd == "continuoussportmode") {
            isContinuous = true;
            Serial.println(">>> 已切换: 持续运动");
            return;
        }
        if (cmd == "pointsportmode") {
            isContinuous = false;
            stopMotors();
            Serial.println(">>> 已切换: 点动模式");
            return;
        }

        // 运动控制
        int speed = 180;
        bool validMove = false;

        if (cmd == "W" || cmd == "w") { controlMecanum(0, speed, 0); validMove = true; }
        else if (cmd == "S" || cmd == "s") { controlMecanum(0, -speed, 0); validMove = true; }
        else if (cmd == "A" || cmd == "a") { controlMecanum(-speed, 0, 0); validMove = true; }
        else if (cmd == "D" || cmd == "d") { controlMecanum(speed, 0, 0); validMove = true; }
        else if (cmd == "Q" || cmd == "q") { controlMecanum(0, 0, speed/2); validMove = true; }
        else if (cmd == "E" || cmd == "e") { controlMecanum(0, 0, -speed/2); validMove = true; }
        else if (cmd == "Z" || cmd == "z") { stopMotors(); isMoving = false; }

        if (validMove) {
            isMoving = true;
            lastMoveTime = millis();
        }
    }
  }
}

// --- [模块B] 运动模式循环检测 ---
void runMotionMode() {
    // 点动模式超时自动停止
    if (!isContinuous && isMoving) {
        if (millis() - lastMoveTime >= 2000) { // 2秒超时
            stopMotors();
            isMoving = false;
            Serial.println(">>> [自动停止] 点动时间到");
        }
    }
    delay(20);
}

// --- [模块C] 语音交互逻辑 (VAD) ---
void runVoiceMode() {
  // 1. 等待触发信号
  if (voiceTrigger == false) {
      return; 
  }
  voiceTrigger = false; 

  // 检查 Token
  if (baidu_access_token == "") {
     Serial.println("Token 无效，重试...");
     baidu_access_token = getAccessToken(baidu_api_key, baidu_secret_key);
     if(baidu_access_token == "") { delay(1000); return; }
  }

  // 申请录音内存
  uint8_t* pcm_data = (uint8_t*)ps_malloc(BUFFER_SIZE);
  if (pcm_data == NULL) {
    Serial.println("PSRAM Error"); 
    delay(1000); 
    return;
  }

  Serial.println(">>> 正在聆听..."); 
  clearAudio();
  
  size_t bytes_read = 0;
  size_t recordingSize = 0;
  int16_t data[512];
  
  unsigned long lastVoiceTime = millis(); 
  bool hasSpoken = false;                 

  // 2. VAD 录音循环
  while (true) {
    // [打断检测]
    if (MySerial.available()) {
       Serial.println(">>> 录音被打断");
       free(pcm_data);
       return; 
    }

    i2s_read(I2S_NUM_0, data, sizeof(data), &bytes_read, portMAX_DELAY);
    
    // 计算音量 & 增益
    long sumVol = 0;
    for (int i = 0; i < bytes_read / 2; i++) {
      int32_t val = data[i] * 50; 
      if (val > 32767) data[i] = 32767;
      else if (val < -32768) data[i] = -32768;
      else data[i] = (int16_t)val;
      sumVol += abs(data[i]);
    }
    int avgVol = sumVol / (bytes_read / 2);

    // VAD 判定
    if (avgVol > VAD_THRESHOLD) {
        lastVoiceTime = millis();
        if (!hasSpoken) {
            Serial.println("检测到语音...");
            hasSpoken = true;
        }
    } 
    
    // 静音超时停止
    if (hasSpoken && (millis() - lastVoiceTime > VAD_SILENCE_MS)) {
        Serial.println("说话结束");
        break; 
    }
    
    // 初始超时停止
    if (!hasSpoken && (millis() - lastVoiceTime > 10000)) {
        Serial.println("超时无人说话");
        free(pcm_data);
        return; 
    }

    // 存入内存
    if (recordingSize + bytes_read <= BUFFER_SIZE) {
        memcpy(pcm_data + recordingSize, data, bytes_read);
        recordingSize += bytes_read;
    } else {
        Serial.println("录音已满");
        break;
    }
  }

  // 过滤短噪音
  if (recordingSize < 16000) { 
      Serial.println("录音太短，忽略");
      free(pcm_data);
      return;
  }

  // [打断检测]
  if (MySerial.available()) { free(pcm_data); return; }

  // 3. 识别 (STT)
  Serial.println(">>> 正在识别...");
  String askText = baiduSTT_Send(baidu_access_token, pcm_data, recordingSize);
  free(pcm_data); 
  clearAudio();

  // [打断检测]
  if (MySerial.available()) return;

  if (askText.length() > 0) {
      Serial.println("Q: " + askText);
      
      // 4. 思考 (LLM)
      Serial.println(">>> 正在思考...");
      String recognizedText = ask_coze(askText);
      
      // [打断检测]
      if (MySerial.available()) return;

      Serial.println("A: " + recognizedText);
      
      // 5. 回复 (TTS)
      Serial.println(">>> 正在合成...");
      baiduTTS_Send(baidu_access_token, recognizedText);
  } else {
      Serial.println("未听到有效声音");
  }

  clearAudio();
}


// =============================================================
//               PART 8: API 实现 (API Implementation)
// =============================================================

// 1. 获取百度 Token
String getAccessToken(const char* api_key, const char* secret_key) {
  HTTPClient http;
  String url = "https://aip.baidubce.com/oauth/2.0/token?grant_type=client_credentials&client_id=" + String(api_key) + "&client_secret=" + String(secret_key);
  http.begin(url);
  int httpCode = http.POST("");
  String access_token = "";
  if (httpCode == HTTP_CODE_OK) {
    String response = http.getString();
    DynamicJsonDocument doc(1024);
    deserializeJson(doc, response);
    access_token = doc["access_token"].as<String>();
  } 
  http.end();
  return access_token;
}

// 2. Coze 对话请求
String ask_coze(const String& question) {
  HTTPClient http;
  http.begin("https://api.coze.cn/open_api/v2/chat");
  http.addHeader("Authorization", "Bearer " + coze_apiKey);
  http.addHeader("Content-Type", "application/json");
  http.addHeader("Connection", "keep-alive");

  DynamicJsonDocument doc(1024);
  doc["bot_id"] = botId;
  doc["user"] = "esp32_user";
  doc["query"] = question;
  doc["stream"] = false;

  String payload;
  serializeJson(doc, payload);
  
  int code = http.POST(payload);
  String answer = "我不知道怎么回答";
  
  if(code == HTTP_CODE_OK) {
    String resp = http.getString();
    DynamicJsonDocument resDoc(4096);
    DeserializationError error = deserializeJson(resDoc, resp);
    
    if (!error) {
      if (resDoc.containsKey("messages")) {
        JsonArray msgs = resDoc["messages"];
        for (JsonObject msg : msgs) {
           if (msg["type"] == "answer") {
               answer = msg["content"].as<String>();
               break;
           }
        }
      }
    }
  }
  http.end();
  return answer;
}

// 3. 百度 STT (语音转文字)
String baiduSTT_Send(String access_token, uint8_t* audioData, int audioDataSize) {
  String recognizedText = "";
  if (access_token == "") return recognizedText;

  int encodedLen = (audioDataSize + 2) / 3 * 4;
  char* audioDataBase64 = (char*)ps_malloc(encodedLen + 1);
  if (!audioDataBase64) {
    Serial.println("STT RAM Error");
    return recognizedText;
  }

  custom_base64_encode(audioDataBase64, audioData, audioDataSize);
  
  String json = "{\"format\":\"pcm\",\"rate\":16000,\"dev_pid\":1537,\"channel\":1,\"cuid\":\"ESP32\",\"token\":\"" + access_token + "\",\"len\":" + String(audioDataSize) + ",\"speech\":\"" + String(audioDataBase64) + "\"}";

  HTTPClient http_client;
  http_client.begin("http://vop.baidu.com/server_api");
  http_client.addHeader("Content-Type", "application/json");
  int httpCode = http_client.POST(json);

  if (httpCode == HTTP_CODE_OK) {
      String response = http_client.getString();
      DynamicJsonDocument responseDoc(2048);
      deserializeJson(responseDoc, response);
      if (responseDoc.containsKey("result"))
         recognizedText = responseDoc["result"][0].as<String>();
  } else {
    Serial.printf("STT HTTP Error: %s\n", http_client.errorToString(httpCode).c_str());
  }

  free(audioDataBase64);
  http_client.end();
  clearAudio();
  return recognizedText;
}

// 4. 百度 TTS (文字转语音)
void baiduTTS_Send(String access_token, String text) {
  if (access_token == "" || text.length() == 0) return;

  Serial.println(">>> [TTS] 播放中...");
  String encodedText = urlEncode(text);
  String url = "https://tsn.baidu.com/text2audio";
  url += "?tok=" + access_token;
  url += "&tex=" + encodedText;
  url += "&per=103&spd=5&pit=5&vol=13&aue=4&cuid=esp32s3&lan=zh&ctp=1";

  const char* header[] = { "Content-Type", "Content-Length" };

  HTTPClient http;
  http.begin(url);
  http.collectHeaders(header, 2);

  int httpResponseCode = http.GET();
  if (httpResponseCode > 0) {
    if (httpResponseCode == HTTP_CODE_OK) {
      String contentType = http.header("Content-Type");
      if (contentType.startsWith("audio")) {
        Stream* stream = http.getStreamPtr();
        uint8_t buffer[1024]; 
        unsigned long lastDataTime = millis(); 
        
        while (http.connected()) {
          // [打断检测]
          if (MySerial.available()) {
              Serial.println("TTS被指令打断");
              break; 
          }
          
          size_t bytesRead = stream->readBytes(buffer, sizeof(buffer));
          if(bytesRead > 0) {
            playAudio(buffer, bytesRead);
            lastDataTime = millis(); 
          } else {
            // 超时判定 (300ms)
            if (millis() - lastDataTime >= 300) {
                Serial.println("播放超时");
                break;
            }
          }
        }
      } else {
        Serial.println("TTS Error: " + http.getString());
      }
    } else {
      Serial.println("Failed to receive audio file");
    }
  } else {
    Serial.printf("HTTP Error: %d\n", httpResponseCode);
  }
  http.end();
  clearAudio();
}


// =============================================================
//               PART 9: 底层驱动与工具 (Low-level Drivers)
// =============================================================

// I2S 播放
void playAudio(uint8_t* audioData, size_t audioDataSize) {
  size_t bytes_written = 0;
  i2s_write(I2S_NUM_1, (int16_t*)audioData, audioDataSize, &bytes_written, portMAX_DELAY);
}

// 播放静音片段
void playSilence() {
  uint8_t silence[1024];
  memset(silence, 0, 1024);
  playAudio(silence, 1024);
  playAudio(silence, 1024);
  playAudio(silence, 1024);
}

// 清空 I2S 缓存
void clearAudio(void) {
  i2s_zero_dma_buffer(I2S_NUM_1); 
  i2s_zero_dma_buffer(I2S_NUM_0); 
}

// 手写 Base64 编码 (无第三方库依赖)
const char b64_tbl[] = "ABCDEFGHIJKLMNOPQRSTUVWXYZabcdefghijklmnopqrstuvwxyz0123456789+/";
void custom_base64_encode(char* out, uint8_t* in, int len) {
    int i=0, j=0, enc=0; unsigned char a3[3], a4[4];
    while (len--) {
        a3[i++] = *(in++);
        if (i == 3) {
            a4[0] = (a3[0]&0xfc)>>2; a4[1] = ((a3[0]&0x03)<<4)+((a3[1]&0xf0)>>4);
            a4[2] = ((a3[1]&0x0f)<<2)+((a3[2]&0xc0)>>6); a4[3] = a3[2]&0x3f;
            for(i=0;i<4;i++) out[enc++] = b64_tbl[a4[i]];
            i=0;
        }
    }
    if (i) {
        for(j=i;j<3;j++) a3[j]='\0';
        a4[0] = (a3[0]&0xfc)>>2; a4[1] = ((a3[0]&0x03)<<4)+((a3[1]&0xf0)>>4);
        a4[2] = ((a3[1]&0x0f)<<2)+((a3[2]&0xc0)>>6); a4[3] = a3[2]&0x3f;
        for(j=0;j<i+1;j++) out[enc++] = b64_tbl[a4[j]];
        while(i++<3) out[enc++]='=';
    }
    out[enc] = '\0';
}

// 电机引脚初始化
void setupMotors() {
  pinMode(PIN_FL_IN1, OUTPUT); pinMode(PIN_FL_IN2, OUTPUT); pinMode(PIN_FL_PWM, OUTPUT);
  pinMode(PIN_FR_IN1, OUTPUT); pinMode(PIN_FR_IN2, OUTPUT); pinMode(PIN_FR_PWM, OUTPUT);
  pinMode(PIN_RL_IN1, OUTPUT); pinMode(PIN_RL_IN2, OUTPUT); pinMode(PIN_RL_PWM, OUTPUT);
  pinMode(PIN_RR_IN1, OUTPUT); pinMode(PIN_RR_IN2, OUTPUT); pinMode(PIN_RR_PWM, OUTPUT);
  stopMotors();
}

// 电机停车
void stopMotors() { controlMecanum(0, 0, 0); }

// 麦克纳姆轮运动解算
void controlMecanum(int x, int y, int w) {
  setMotorSpeed(PIN_FL_IN1, PIN_FL_IN2, PIN_FL_PWM, y + x + w);
  setMotorSpeed(PIN_FR_IN1, PIN_FR_IN2, PIN_FR_PWM, y - x - w);
  setMotorSpeed(PIN_RL_IN1, PIN_RL_IN2, PIN_RL_PWM, y - x + w);
  setMotorSpeed(PIN_RR_IN1, PIN_RR_IN2, PIN_RR_PWM, y + x - w);
}

// 单个电机驱动
void setMotorSpeed(int p1, int p2, int pwm, int s) {
  if (s>255) s=255; if (s<-255) s=-255;
  if (s>0) { digitalWrite(p1, HIGH); digitalWrite(p2, LOW); analogWrite(pwm, s); }
  else if (s<0) { digitalWrite(p1, LOW); digitalWrite(p2, HIGH); analogWrite(pwm, -s); }
  else { digitalWrite(p1, LOW); digitalWrite(p2, LOW); analogWrite(pwm, 0); }
}
